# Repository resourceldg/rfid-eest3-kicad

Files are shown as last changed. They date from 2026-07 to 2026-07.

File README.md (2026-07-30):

# Control de acceso RFID EEST3

Diseño electrónico en KiCad 10 para un sistema de acceso escolar basado en ESP32, RC522, sensores y control de cerradura de 12 V.

## Estado actual del proyecto

Hay una placa de prueba de 140 × 100 mm, doble cara, **ruteada y con el DRC
limpio**: 348 pistas, 8 vías, dos planos de masa separados que se tocan en un
solo punto, y ninguna infracción de margen, cobre, alivio térmico ni
serigrafía. Los tres "no conectados" que informa el DRC son deliberados.

**No está lista para fabricar.** Faltan las mediciones de banco, la
verificación mecánica de los conectores y, sobre todo, medir el módulo ESP32-S3
para borrar la hilera de pines que sobra en J13. Los tres bloqueos están
detallados en [PENDIENTES.md](rfid-control-acceso-eest3/PENDIENTES.md).

## Ver todo el circuito de un vistazo

Las seis hojas del esquema son el documento valido, pero estan separadas y la
hoja raiz no dibuja como se relacionan. Para eso esta
[RESUMEN_ELECTRICO.kicad_sch](rfid-control-acceso-eest3/RESUMEN_ELECTRICO.kicad_sch):
una sola hoja A2 con los 67 componentes, sus simbolos y valores, el cableado de
cada bloque y el ESP32 en el centro. Es documentacion y **no forma parte de la
jerarquia del proyecto**: se abre sola.

```sh
python3 tools/esquema_resumen.py     # regenera la hoja desde el netlist real
kicad-cli sch export pdf -o rfid-control-acceso-eest3/RESUMEN_ELECTRICO.pdf \
    rfid-control-acceso-eest3/RESUMEN_ELECTRICO.kicad_sch
```

El generador se verifica solo: exporta el netlist de la hoja que acaba de
escribir y lo compara nodo por nodo contra el de las seis hojas. Si no coincide,
falla.

## Documentos de referencia

- Qué falta para fabricar: [rfid-control-acceso-eest3/PENDIENTES.md](rfid-control-acceso-eest3/PENDIENTES.md)
- Revisión técnica y riesgos: [rfid-control-acceso-eest3/INFORME_ESQUEMA.md](rfid-control-acceso-eest3/INFORME_ESQUEMA.md)
- Mediciones que faltan: [rfid-control-acceso-eest3/CHECKLIST_PREPCB.md](rfid-control-acceso-eest3/CHECKLIST_PREPCB.md)
- Por qué el cobre está donde está: [rfid-control-acceso-eest3/GUIA_RUTEO.md](rfid-control-acceso-eest3/GUIA_RUTEO.md)

## Próximo paso recomendado

Medir la separación real entre hileras del ESP32-S3 DevKit y borrar la hilera
sobrante de J13. Es el único bloqueo que no necesita instrumental: alcanza con
un calibre y el módulo en la mano.

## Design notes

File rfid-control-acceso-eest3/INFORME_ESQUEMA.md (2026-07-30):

# Informe técnico — Control de acceso RFID EEST3

Fecha: 2026-07-29  
Etapa: PCB prototipo Rev. A — transferencia y prelayout autorizados; ruteo no autorizado.

Datos físicos y comerciales disponibles:

- Marca publicada: Roa/Olipe SEB.
- Modelo publicado: 150.
- Tipo: cerradura eléctrica empotrable para portero eléctrico.
- Alimentación confirmada físicamente: 12 VCC.
- Consumo nominal confirmado: 1,8 A.
- Potencia nominal: 12 V × 1,8 A = 21,6 W.
- Fuente disponible: 12 VCC / 2,5 A (30 W).
- Pendientes: medición de corriente de arranque y comprobación térmica
  del MOSFET.

## Arquitectura implementada

El esquema se organizó jerárquicamente en seis bloques:

1. Alimentación y protección de 12 V, buck a 5 V y distribución de 3,3 V.
2. Controlador ESP32-S3-DevKitC-1 N16R8 de 44 pines representado mediante
   dos conectores funcionales de 1×22.
3. Lector RC522 representado mediante conector funcional de ocho vías.
4. Sensor reed, PIR opcional y entrada futura de sensor de gabinete.
5. LEDs de estado y buzzer con etapa MOSFET.
6. Etapa MOSFET canal N low-side para la cerradura inductiva de 12 VCC.

Las redes globales principales son `+12V_IN`, `+12V_LOCK`, `+5V`, `+3V3`
y `GND`. El RC522 solo está conectado a `+3V3`.

## Componentes

### Alimentación

- J1: entrada de 12 V.
- D1: protección serie Schottky, selección pendiente.
- F1: fusible lento o PTC de aproximadamente 2,5 A, valor preliminar;
  debe validarse después de medir la corriente de arranque.
- C1: 1000 µF / 25 V preliminar como reserva local de 12 V.
- C2: 100 nF preliminar.
- J2: interfaz funcional para módulo buck 12 V a 5 V.
- C3: 470 µF / 10 V preliminar en la salida de 5 V.
- C4: 100 nF preliminar.
- D5: TVS bidireccional para la línea de 12 V, selección pendiente.

### Controlador y RFID

- J13: representación unificada de 44 contactos (dos hileras de 22) del
  `ESP32_S3_DEVKITC1_N16R8_44PIN`, basada en el pinout del
  ESP32-S3-DevKitC-1. La equivalencia mecánica del clon YD-ESP32-S3 sigue
  pendiente de medición.
- C5: desacoplamiento de 100 nF preliminar.
- J5: interfaz funcional RC522; orden físico `PENDIENTE_DATASHEET`.
- C6: desacoplamiento de 100 nF preliminar.
- C9: reserva local de 10 µF preliminar.
- R9/R10/R11/R12: 33 Ω serie en `RFID_SS`, `RFID_SCK`, `RFID_MOSI` y
  `RFID_RST`, respectivamente.

### Sensores

- J6: reed de puerta, previsto para contacto normalmente cerrado.
- R1: pull-up 10 kΩ preliminar.
- C7: filtro 100 nF preliminar.
- J7: alimentación y contacto NC de alarma del DSC LC-100.
- J8: sensor óptico/de gabinete futuro.
- J10: contacto NC de tamper del DSC LC-100.
- R2: pull-up externo 10 kΩ para `CABINET_SENSOR` en GPIO6.
- D6: TVS para `DOOR_REED`, selección 3,3 V pendiente.
- D7: TVS preliminar sobre `PIR_CONTACT`; selección pendiente.
- D8: TVS para `CABINET_SENSOR`, selección 3,3 V pendiente.
- C8: filtro de 100 nF preliminar para `CABINET_SENSOR`.
- R13/R15: pull-ups externos de 10 kΩ para alarma y tamper.
- R14/R16: resistencias serie de 1 kΩ hacia GPIO5 y GPIO7.
- C10/C11: filtros de 100 nF desde `PIR_IN` y `PIR_TAMPER` a GND.

### Señalización

- R3/D2: LED verde con 330 Ω preliminar.
- R4/D3: LED rojo con 330 Ω preliminar.
- BZ1: `PENDIENTE_TIPO_BUZZER`.
- Q1, R5 y R6: driver MOSFET, 100 Ω serie y 10 kΩ pull-down.

### Cerradura

- J9: cerradura inductiva confirmada de 12 VCC, 1,8 A y 21,6 W.
- Q2: AO3400A preliminar, MOSFET canal N de nivel lógico.
- R7: 100 Ω en serie con el gate.
- R8: 10 kΩ entre gate y `GND_POWER`.
- D4: SS3A4 preliminar, Schottky de 3 A / 40 V.
- NT1: unión explícita en estrella entre `GND_POWER` y `GND`.

Todos los footprints están asignados y resueltos contra bibliotecas reales de KiCad 10; no queda ningún `PLACEHOLDER_NO_FABRICAR`. El único footprint local es `rfid_eest3:ESP32-S3-44P_SOCKET_DUAL_22.86_25.40`.

## Presupuesto de alimentación de la placa

El consumo de la electrónica todavía es una estimación porque faltan la
revisión física exacta del clon ESP32-S3, PIR, buzzer y buck.

| Carga | Reserva estimada | Potencia aproximada |
|---|---:|---:|
| ESP32 DevKit, incluyendo picos de radio y regulador | 500 mA a 5 V | 2,50 W |
| RC522 y pérdidas de regulación asociadas | 50 mA a 3,3 V | 0,17 W |
| DSC LC-100 y sensores externos | consumo pendiente a 12 V | debe medirse |
| Dos LEDs | 20 mA total a 3,3 V | 0,07 W |
| Buzzer | 100 mA a 5 V | 0,50 W |
| Margen/pérdidas del buck | eficiencia supuesta 85 % | aproximadamente 0,6 W |

La electrónica de baja tensión demanda aproximadamente 0,4 A desde 12 V.
Sumada a la cerradura, la corriente nominal estimada es aproximadamente
2,2 A. La fuente de 12 VCC / 2,5 A puede utilizarse para el prototipo, pero
deja solamente unos 0,3 A de margen nominal y debe verificarse durante el
arranque y la activación de la cerradura.

Para la instalación definitiva se recomienda una fuente regulada de
12 V / 4 A o superior, con protección y respuesta transitoria apropiadas.

## Etapa principal de cerradura 12 VCC

La cerradura está conectada entre `+12V_LOCK` y `LOCK_OUT`.
El drain de Q2 se conecta a `LOCK_OUT`; el source, a `GND_POWER`.
`LOCK_GATE` llega al gate mediante R7 de 100 Ω y R8 mantiene el gate apagado
con 10 kΩ hacia `GND_POWER`.

D4 está conectado en paralelo con la carga inductiva: cátodo hacia
`+12V_LOCK` y ánodo hacia `LOCK_OUT`. La selección preliminar es SS3A4,
3 A / 40 V.

Q2 se mantiene preliminarmente como AO3400A. Usando 1,8 A y
`RDS(on) = 48 mΩ`, la disipación conductiva teórica es:

`P = I² × R = (1,8 A)² × 0,048 Ω ≈ 0,156 W`.

Este cálculo no sustituye la comprobación térmica, el análisis del
encapsulado ni la verificación de `RDS(on)` a la tensión de gate real.

## Protección de sobrecorriente

F1 quedó como `T3.15A_5x20_LITTELFUSE_215`. ATENCIÓN: 3,15 A no protege una fuente de 2,5 A, que pliega antes; hay que reconciliar el valor del fusible con la fuente elegida.
No debe utilizarse una protección rápida de 2 A porque podría actuar durante
el funcionamiento nominal. La elección definitiva depende de medir la
corriente de arranque y revisar la curva tiempo-corriente.

## Retornos y filtrado

El esquema distingue:

- `GND_POWER`: retorno de Q2, cerradura, TVS de alimentación y capacitores
  de 12 V;
- `GND`: retorno lógico de buck, ESP32, RC522, sensores y señalización;
- NT1 `STAR_GND`: única unión lógica entre ambos retornos, próxima a la
  entrada de alimentación.

La masa es común porque Q2 es controlado desde el ESP32. El retorno de
1,8 A de la cerradura debe mantenerse físicamente separado del retorno
lógico y unirse a éste solamente en NT1, cerca de la entrada de alimentación.

Filtrado preliminar:

- 1000 µF / 25 V más 100 nF sobre 12 V;
- 470 µF / 10 V más 100 nF sobre 5 V;
- 100 nF locales en ESP32 y RC522.

Los electrolíticos deben seleccionarse por ESR, ripple, temperatura y
tolerancia. Estos valores reducen transitorios breves pero no sustituyen una
fuente con margen ni una distribución de masa correcta.

## Controlador ESP32-S3

Controlador confirmado por la publicación:

- familia ESP32-S3;
- placa ESP32-S3-DevKitC-1 N16R8 o clon compatible YD-ESP32-S3;
- flash de 16 MB;
- PSRAM de 8 MB;
- 44 pines físicos, 22 por lado;
- representación temporal:
  `ESP32_S3_DEVKITC1_N16R8_44PIN`.

No se utiliza ningún símbolo ni pinout de ESP32-WROOM-32 clásico de 30 o
38 pines. No se asume que el clon tenga las dimensiones mecánicas de la
placa oficial.

Restricciones aplicadas:

- GPIO22, GPIO23, GPIO24 y GPIO25 no existen en ESP32-S3.
- GPIO26 a GPIO32 quedan excluidos por su relación con flash/PSRAM.
- GPIO33 a GPIO37 quedan excluidos por la PSRAM de la variante N16R8.
- GPIO0, GPIO3, GPIO45 y GPIO46 quedan excluidos por strapping.
- GPIO19 y GPIO20 quedan reservados para USB nativo.
- GPIO43 y GPIO44 quedan reservados para UART de diagnóstico.
- GPIO38 se evita porque puede controlar el LED RGB según la revisión.

Continúan como `PENDIENTE_MEDICIÓN`: separación entre hileras, dimensiones,
posición de ambos USB-C del clon, distancia de los pines al borde, botones y
orientación de la antena.

## Mapa GPIO

| Señal | GPIO | Uso |
|---|---:|---|
| RFID_SCK | 12 | salida SPI; R10 = 33 Ω |
| RFID_MISO | 13 | entrada SPI |
| RFID_MOSI | 11 | salida SPI; R11 = 33 Ω |
| RFID_SS | 10 | salida chip-select; R9 = 33 Ω |
| RFID_RST | 9 | salida reset; R12 = 33 Ω |
| DOOR_REED | 4 | entrada con pull-up externo |
| PIR_IN | 5 | entrada desde contacto NC, serie 1 kΩ y filtro 100 nF |
| CABINET_SENSOR | 6 | entrada con pull-up externo |
| PIR_TAMPER | 7 | entrada desde contacto NC, serie 1 kΩ y filtro 100 nF |
| LED_OK | 15 | salida |
| LED_ERROR | 16 | salida |
| BUZZER | 17 | salida hacia driver |
| LOCK_GATE | 18 | salida hacia driver |

## Sensor PIR DSC LC-100

El sensor confirmado es un DSC LC-100 alimentado desde `+12V_AUX` y GND.
La alimentación está separada conceptualmente de las señales de alarma y
tamper, que son contactos secos de relé normalmente cerrados.

La interfaz física quedó dividida en tres borneras independientes:

- J11 `PIR_PWR`: pin 1 a `+12V_AUX`, pin 2 a GND;
- J12 `PIR_ALARM`: pin 1 COM a GND, pin 2 NC a `PIR_CONTACT`;
- J10 `PIR_TAMPER`: pin 1 T1 a `PIR_TAMPER_CONTACT`, pin 2 T2 a GND.

Contacto de alarma:

- COM a GND;
- NC a `PIR_CONTACT`;
- R13 de 10 kΩ entre `PIR_CONTACT` y `+3V3`;
- R14 de 1 kΩ entre `PIR_CONTACT` y `PIR_IN`;
- C10 de 100 nF entre `PIR_IN` y GND.

En estado normal el contacto está cerrado y GPIO5 permanece en nivel bajo.
Una alarma, corte del cable o desconexión abre el circuito y el pull-up lleva
GPIO5 a nivel alto.

Contacto tamper:

- un terminal a GND;
- otro terminal a `PIR_TAMPER_CONTACT`;
- R15 de 10 kΩ entre `PIR_TAMPER_CONTACT` y `+3V3`;
- R16 de 1 kΩ entre `PIR_TAMPER_CONTACT` y `PIR_TAMPER`;
- C11 de 100 nF entre `PIR_TAMPER` y GND.

La rama `+12V_AUX` se deriva de `+12V_LOCK` mediante F2
`AUX_PROTECTION_PENDING`. Para el DSC LC-100 solo quedan pendientes la
numeración física exacta de sus borneras, la medición del cableado y la
ubicación física del sensor.

## RC522

El conector funcional J5 representa, en este orden lógico:

1. `RFID_SS`
2. `RFID_SCK`
3. `RFID_MOSI`
4. `RFID_MISO`
5. `RFID_IRQ`, marcado explícitamente No Connect
6. `GND`
7. `RFID_RST`
8. `+3V3`

Este orden no autoriza fabricar un conector físico. Debe verificarse el módulo
real y su datasheet antes de asignar footprint.

## Datos pendientes

- Capacidad de corriente disponible en 3,3 V de la revisión física del
  ESP32-S3 DevKit/clon.
- Correspondencia física final del clon YD-ESP32-S3 con los headers oficiales.
- Pinout físico exacto del módulo RC522.
- Modelo del buck y disposición de terminales.
- Medir la corriente de arranque de la cerradura.
- Comprobar térmicamente Q2 en las condiciones reales de activación.
- Confirmar la `RDS(on)` del AO3400A a la tensión de gate real del ESP32.
- Curva exacta del fusible lento o PTC de placa.
- Numeración física exacta de las borneras del DSC LC-100.
- Medición del cableado del DSC LC-100.
- Ubicación física del DSC LC-100.
- Tipo, tensión y corriente del buzzer; necesidad de diodo si fuera inductivo.

## Lista de comprobación física previa a footprints

Estados utilizados:

- `CONFIRMADO`: dato físico disponible y utilizable.
- `PENDIENTE_MEDICIÓN`: requiere medir el ejemplar real o el montaje.
- `PENDIENTE_MODELO`: requiere seleccionar o identificar el componente y
  consultar su documentación.

No debe asignarse ningún footprint hasta completar los datos aplicables de
esta lista.

Conteo verificado de filas de comprobación —sin contar la leyenda de
estados—:

- 10 `CONFIRMADO`.
- 24 `PENDIENTE_MEDICIÓN`.
- 21 `PENDIENTE_MODELO`.
- Total: **55 verificaciones**.

El conteo anterior de 7, 25 y 26 incluía una vez adicional cada estado por
su aparición en la leyenda. No se encontraron filas duplicadas y no se
eliminó ninguna verificación válida.

| Estado | Bloque | Dato físico o eléctrico | Criterio de aceptación / acción requerida |
|---|---|---|---|
| `CONFIRMADO` | ESP32-S3 DevKit | Familia y variante objetivo | ESP32-S3-DevKitC-1 N16R8 o clon YD-ESP32-S3 compatible; 16 MB flash y 8 MB PSRAM. |
| `CONFIRMADO` | ESP32-S3 DevKit | Cantidad de pines | 44 pines, 22 por hilera. |
| `PENDIENTE_MEDICIÓN` | ESP32-S3 DevKit | Separación entre hileras | Medir entre centros con calibre; no asumir la dimensión oficial para el clon. |
| `PENDIENTE_MEDICIÓN` | ESP32-S3 DevKit | Paso de pines | Medir y contrastar con el módulo físico antes de crear el footprint. |
| `PENDIENTE_MEDICIÓN` | ESP32-S3 DevKit | Largo, ancho y altura máxima | Medir placa, componentes salientes y conectores montados. |
| `PENDIENTE_MEDICIÓN` | ESP32-S3 DevKit | USB, botones y antena | Medir ambos USB-C del clon, EN, BOOT, orientación de antena y distancias a bordes. |
| `CONFIRMADO` | ESP32-S3 DevKit | Pinout lógico de referencia | J3/J4 representan los headers J1/J3 del DevKitC-1 oficial; validar continuidad contra el clon físico antes de PCB. |
| `PENDIENTE_MEDICIÓN` | RC522 | Orden real del conector | Verificar continuidad y serigrafía pin por pin; el orden lógico de J5 no define el orden físico. |
| `PENDIENTE_MEDICIÓN` | RC522 | Paso, posición y orientación | Medir conector, distancia a bordes y sentido de inserción. |
| `PENDIENTE_MEDICIÓN` | RC522 | Dimensiones y agujeros | Medir largo, ancho, altura y centros de fijación del módulo real. |
| `PENDIENTE_MODELO` | RC522 | Zona de exclusión de antena | Obtener la recomendación del fabricante sobre cobre, planos de masa, metal y batería/cerradura. |
| `PENDIENTE_MEDICIÓN` | RC522 | Separación en el montaje | Validar experimentalmente lectura RFID con la antena alejada de cobre, cableado de 1,8 A, MOSFET, buck y cerradura. |
| `PENDIENTE_MODELO` | Buck | Modelo exacto | Seleccionar módulo o regulador y conseguir plano mecánico y datasheet. |
| `PENDIENTE_MODELO` | Buck | Entrada, salida y polaridad | Confirmar rango de entrada, tensión de salida regulada a 5 V y orden real de terminales. |
| `PENDIENTE_MEDICIÓN` | Buck | Dimensiones y altura | Medir PCB, componentes, inductor, disipador, potenciómetro y agujeros. |
| `PENDIENTE_MEDICIÓN` | Buck | Terminales | Medir paso, posición, orientación y acceso para ajuste o cableado. |
| `PENDIENTE_MODELO` | Buck | Capacidad de corriente | Debe cubrir la electrónica con picos de radio y margen térmico; objetivo mínimo recomendado: 5 V / 1 A continuo, sujeto al consumo real. |
| `CONFIRMADO` | MOSFET Q2 | Corriente nominal de carga | 1,8 A con la cerradura activada. |
| `CONFIRMADO` | MOSFET Q2 | Cálculo conductivo preliminar | Para 48 mΩ: `(1,8 A)² × 0,048 Ω ≈ 0,156 W`. |
| `PENDIENTE_MODELO` | MOSFET Q2 | AO3400A y fabricante | Verificar datasheet del fabricante concreto, `VDS`, corriente, SOA y `RDS(on)` garantizada con `VGS` de 2,5 V o compatible con 3,3 V. No aceptar únicamente el dato a 10 V. |
| `PENDIENTE_MEDICIÓN` | MOSFET Q2 | Gate real | Medir la tensión de gate en nivel alto con el ESP32 y la etapa funcionando. |
| `PENDIENTE_MEDICIÓN` | MOSFET Q2 | Temperatura | Medir temperatura ambiente y elevación de Q2 durante el peor tiempo de activación. |
| `PENDIENTE_MEDICIÓN` | MOSFET Q2 | Cobre disponible | Definir área de cobre, vías térmicas y espesor de cobre antes de validar SOT-23. |
| `PENDIENTE_MODELO` | MOSFET Q2 | Alternativa térmica | Comparar AO3400A SOT-23 con un MOSFET lógico en SO-8 térmico, PowerPAK/LFPAK o DPAK; elegir por `RDS(on)` a gate real, SOA, disipación, disponibilidad y montaje educativo. |
| `PENDIENTE_MEDICIÓN` | MOSFET Q2 | Transitorios | Medir `VDS` durante apertura y cierre; mantener margen respecto de la tensión máxima del dispositivo. |
| `CONFIRMADO` | Gate Q2 | Red de control | R7 = 100 Ω y R8 = 10 kΩ pull-down. |
| `CONFIRMADO` | Flyback D4 | Requisitos preliminares | Schottky de al menos 3 A y 40 V; cátodo a `+12V_LOCK`, ánodo a `LOCK_OUT`. |
| `PENDIENTE_MODELO` | Flyback D4 | SS3A4 exacto | Confirmar fabricante, código completo, corriente media, corriente de pulso, tensión inversa, fuga y curva térmica. |
| `PENDIENTE_MODELO` | Flyback D4 | Encapsulado | Confirmar encapsulado y dimensiones reales; el nombre comercial no autoriza asumir SMA/SMB. |
| `PENDIENTE_MEDICIÓN` | Flyback D4 | Régimen térmico | Comprobar temperatura y energía por maniobra con la corriente y frecuencia reales. |
| `PENDIENTE_MEDICIÓN` | Flyback D4 | Ubicación física | Reservar ubicación inmediatamente junto a J9 y al lazo de corriente de la cerradura; minimizar el área del lazo. |
| `CONFIRMADO` | Protección | Fuente de prototipo | 12 VCC / 2,5 A; utilizable para el prototipo con margen nominal limitado. |
| `CONFIRMADO` | Protección | Fuente definitiva recomendada | Fuente regulada de 12 V / 4 A o superior. |
| `PENDIENTE_MEDICIÓN` | Protección | Corriente de arranque | Medir pico, duración y repetibilidad antes de fijar fusible o PTC. |
| `PENDIENTE_MODELO` | Protección | Fusible lento | Comparar corriente nominal, curva tiempo-corriente, poder de corte, tensión máxima y portafusible. |
| `PENDIENTE_MODELO` | Protección | PTC | Comparar corriente de mantenimiento, corriente de disparo, tensión máxima, resistencia fría/caliente y tiempo de recuperación. |
| `PENDIENTE_MODELO` | Protección | Separación por ramas | Proponer una protección para la electrónica después de la derivación y otra para `+12V_LOCK`; sus valores se eligen después de medir consumos y arranque. |
| `PENDIENTE_MODELO` | Conectores de potencia | Corriente nominal | J1 y J9 deben superar la corriente continua y de arranque con margen; objetivo preliminar mínimo 5 A por contacto. |
| `PENDIENTE_MODELO` | Conectores de potencia | Paso y cable | Seleccionar paso, sección admitida, temperatura, tensión y sistema de tornillo/resorte según el cable real. |
| `PENDIENTE_MODELO` | Conectores | Polaridad y retención | Elegir conectores polarizados o rotulado inequívoco; definir punteras, terminales y alivio de tracción. |
| `PENDIENTE_MEDICIÓN` | Conectores | Separación física | Definir distancia entre potencia, señales, antena y bordes; evitar recorridos paralelos largos entre `LOCK_OUT` y sensores. |
| `PENDIENTE_MODELO` | Reed | Modelo físico | Confirmar contacto NC, corriente/tensión de contacto, cable, carcasa, fijación y conector. |
| `CONFIRMADO` | PIR DSC LC-100 | Modelo e interfaz | Alimentación a 12 V y contactos secos NC independientes para alarma y tamper; no es una salida electrónica de 5 V. |
| `PENDIENTE_MEDICIÓN` | PIR DSC LC-100 | Instalación física | Confirmar numeración de borneras, medir cableado y definir ubicación física. |
| `PENDIENTE_MODELO` | Sensor de gabinete | Modelo físico | Confirmar tipo de salida, tensión, consumo, cable y conector. |
| `PENDIENTE_MODELO` | Buzzer | Tipo físico | Confirmar activo/pasivo, tensión, corriente, polaridad, diámetro, altura, paso y necesidad de diodo. |
| `PENDIENTE_MODELO` | LEDs | Formato | Elegir THT/SMD, color, corriente objetivo, polaridad, dimensiones y visibilidad a través de la caja. |
| `PENDIENTE_MODELO` | Capacitores | Tecnología y tensión | Confirmar electrolíticos de 1000 µF/25 V y 470 µF/10 V, ESR, ripple y temperatura; revisar margen de tensión. |
| `PENDIENTE_MEDICIÓN` | Capacitores | Geometría | Medir diámetro, altura y paso; comprobar polaridad y espacio de montaje. |
| `PENDIENTE_MODELO` | Capacitores | Cerámicos | Elegir encapsulado, tensión, dieléctrico y tolerancia para los 100 nF. |
| `PENDIENTE_MEDICIÓN` | Mecánica | Dimensiones de placa | Definir largo, ancho, altura máxima y zonas prohibidas de la caja. |
| `PENDIENTE_MEDICIÓN` | Mecánica | Fijación | Definir cantidad, diámetro, posición y despeje de agujeros, separadores y tornillos. |
| `PENDIENTE_MODELO` | Mecánica | Caja | Seleccionar material, ventilación, grado de protección, acceso de mantenimiento y puesta a tierra si correspondiera. |
| `PENDIENTE_MEDICIÓN` | Mecánica | Acceso | Validar acceso a USB, botones, fusible, buck, conectores y tornillos sin desmontaje peligroso. |
| `PENDIENTE_MEDICIÓN` | Mecánica/RFID | Separación funcional | Ensayar distancia entre antena RC522, etapa MOSFET, buck, cableado de cerradura y cualquier pieza metálica de la caja. |

### Evaluación del MOSFET

- El IRFZ44N queda descartado para control directo desde un GPIO de 3,3 V.
- Su `RDS(on)` está garantizada únicamente con `VGS = 10 V`.
- Su `VGS(th)` de 2 a 4 V indica solamente el comienzo de conducción y no
  representa plena conducción ni baja resistencia para manejar 1,8 A.
- Solo podría utilizarse con un driver de gate que entregue aproximadamente
  10 V, lo que agregaría componentes y complejidad innecesarios.
- Se mantiene el AO3400A como selección preliminar mientras se evalúa una
  alternativa logic-level de encapsulado mayor, con `RDS(on)` garantizada a
  una tensión compatible con el GPIO de 3,3 V.

### Relevamiento físico necesario

| Componente | Marca/modelo | Foto frontal | Foto posterior | Largo | Ancho | Altura | Paso entre pines | Separación entre hileras | Orden físico de pines | Tensión | Corriente | Estado de confirmación |
|---|---|---|---|---|---|---|---|---|---|---|---|---|
|  |  |  |  |  |  |  |  |  |  |  |  |  |
|  |  |  |  |  |  |  |  |  |  |  |  |  |
|  |  |  |  |  |  |  |  |  |  |  |  |  |
|  |  |  |  |  |  |  |  |  |  |  |  |  |
|  |  |  |  |  |  |  |  |  |  |  |  |  |
|  |  |  |  |  |  |  |  |  |  |  |  |  |

### Tratamiento propuesto de las advertencias ERC

- `RFID_IRQ`: IRQ no se utiliza y el pin 5 de J5 quedó marcado
  explícitamente como No Connect.
- `PIR_IN`: la advertencia quedó resuelta mediante el contacto seco NC del
  DSC LC-100, R13/R14 y C10.
- `PIR_TAMPER`: contacto seco NC supervisado mediante R15/R16 y C11.
- No se agregaron exclusiones para ocultar advertencias.

## ERC

Comando: `kicad-cli sch erc`

Resultado final (2026-07-29 07:36:26): **0 errores y 0 advertencias**.

No quedan advertencias aceptadas. `RFID_IRQ` está marcado No Connect y las
dos entradas del DSC LC-100 están conectadas mediante sus respectivas redes
de pull-up, protección serie y filtrado.

No se agregaron exclusiones individuales ni `PWR_FLAG` innecesarios. KiCad
informó como clases de comprobación ignoradas por la configuración:
`Global label only appears once in the schematic`,
`Four connection points are joined together`, `SPICE model issue` y
`Assigned footprint doesn't match footprint filters`. No se modificó esa
configuración durante esta actualización.

## Riesgos eléctricos

- Una numeración incorrecta de las borneras del LC-100 podría intercambiar
  alimentación y contactos; debe verificarse físicamente antes de energizar.
- La corriente de arranque aún desconocida puede producir caídas de tensión
  o disparar la protección.
- La fuente disponible deja solamente unos 0,3 A de margen nominal después
  de sumar la cerradura y la estimación de la electrónica.
- La disipación calculada de Q2 no incluye transitorios ni aumento de
  `RDS(on)` por temperatura.
- El retorno de 1,8 A puede reiniciar o perturbar al ESP32 si no se respeta
  la separación física y la unión en estrella.
- La salida de 3,3 V del DevKit debe verificarse antes de alimentar el RC522.
- Los TVS agregados son topologías preliminares: tensión de trabajo, clamp,
  energía, fuga y capacitancia deben seleccionarse con los cables y módulos reales.

## Preparación de footprints y fabricación

La PCB tiene los 71 footprints colocados sobre un contorno de 140 × 100 mm, sin pistas, vías ni planos. El floorplan se recalculó a partir de la posición real de los pines de J13. Queda pendiente ejecutar **Update PCB from Schematic** en la GUI para transferir los footprints nuevos (KiCad no expone esa operación por CLI). Los nombres se verificaron contra el
índice de footprints de KiCad 10, sincronizado el 2026-07-29: 155 bibliotecas y
15 447 footprints.

Estados:

- `CONFIRMADO`: componente físico y encapsulado suficientemente definidos.
- `PRELIMINAR`: footprint existente y eléctricamente plausible, pendiente de
  comparación con el componente comprado.
- `PENDIENTE_MEDICIÓN`: no debe asignarse hasta medir o identificar el modelo.

| Referencia | Componente | Valor | Footprint propuesto | Estado | Corriente o tensión relevante | Observaciones de montaje | Riesgo de pinout incorrecto |
|---|---|---|---|---|---|---|---|
| R1–R17 | Resistencias THT | 33 Ω, 100 Ω, 330 Ω, 1 kΩ y 10 kΩ según referencia | `Resistor_THT:R_Axial_DIN0207_L6.3mm_D2.5mm_P10.16mm_Horizontal` | PRELIMINAR | 3,3 V/5 V; R7 es serie de gate | DIN0207, 0,25 W, cuerpo 6,3 × 2,5 mm y paso 10,16 mm; confirmar potencia y tamaño real | Bajo: componente no polarizado |
| C2, C4–C8, C10, C11 | Cerámicos THT | 100 nF | `Capacitor_THT:C_Disc_D5.0mm_W2.5mm_P5.00mm` | PRELIMINAR | Confirmar tensión nominal; C2/C4 están en alimentación | Disco 5 × 2,5 mm y paso 5 mm; comparar con el lote comprado | Bajo: no polarizado |
| C1 | Electrolítico radial | 1000 µF / 25 V preliminar | Radial THT por definir | PENDIENTE_MEDICIÓN | 25 V mínimo indicado; entrada de 12 V | Medir diámetro, altura, paso, ESR y ripple; respetar polaridad | Alto si se invierte polaridad o se asume el paso |
| C3 | Electrolítico radial | 470 µF / 10 V preliminar | Radial THT por definir | PENDIENTE_MEDICIÓN | 10 V mínimo indicado; salida de 5 V | Medir diámetro, altura, paso, ESR y ripple; respetar polaridad | Alto si se invierte polaridad o se asume el paso |
| C9 | Capacitor local RC522 | 10 µF preliminar | Radial THT o cerámico por definir | PENDIENTE_MEDICIÓN | 3,3 V | Definir tecnología, polaridad, diámetro/encapsulado y paso | Medio |
| D2, D3 | LED verde/rojo | 5 mm | `LED_THT:LED_D5.0mm` | PRELIMINAR | Corriente limitada por R3/R4 de 330 Ω | Paso 2,54 mm; orientar cara plana/cátodo y asegurar visibilidad desde la caja | Alto si se intercambian A/K |
| Q2 | MOSFET de cerradura | AO3400A preliminar | `Package_TO_SOT_SMD:SOT-23`, asignado al esquema | PRELIMINAR | 12 V, 1,8 A; disipación conductiva teórica ≈0,156 W | Datasheet oficial AOS y símbolo verificados: 1=G, 2=S, 3=D. Validar térmicamente el SOT-23 | Crítico si se compra una variante con pinout diferente |
| Q2 alternativa | MOSFET logic-level reparable | Modelo TO-220 pendiente | `Package_TO_SOT_THT:TO-220-3_Vertical` | PENDIENTE_MEDICIÓN | ≥30 V, ≥5 A y `RDS(on)` garantizada a 2,5/3,3 V | Alternativa para montaje, disipación y reparación; no reemplaza al AO3400A sin aprobación | Crítico: seleccionar modelo real y verificar G-D-S |
| — | MOSFET descartado | IRFZ44N | No asignar | CONFIRMADO | No garantiza conducción adecuada con gate de 3,3 V | Solo sería utilizable con driver de gate cercano a 10 V | Crítico si se conecta directamente al GPIO |
| D4 | Flyback de cerradura | SS3A4, 3 A / 40 V preliminar | `Diode_SMD:D_SMA` | PRELIMINAR | Pulso inicial de al menos 1,8 A | SMA/DO-214AC; colocar junto a J9; pad 1 es K y pad 2 es A en el esquema actual | Alto: confirmar encapsulado SS3A4 y polaridad física |
| Q1 | Driver de buzzer NMOS | AO3400A preliminar | `Package_TO_SOT_SMD:SOT-23`, asignado al esquema | PRELIMINAR | Buzzer a +5 V; corriente pendiente | GPIO17 → R5 100 Ω → gate; R6 10 kΩ gate-source; source a GND; drain al negativo de BZ1. Datasheet oficial AOS y símbolo verificados: 1=G, 2=S, 3=D | Crítico si se adapta por apariencia en vez de verificar pads |
| D9 | Protección opcional del buzzer | `DNP_HASTA_CONFIRMAR_TIPO_BUZZER` | Sin footprint hasta confirmar el buzzer | PENDIENTE_MEDICIÓN | Cátodo a +5 V; ánodo al drain/negativo del buzzer | Montar solamente si BZ1 es magnético/inductivo. Un piezoeléctrico normalmente no requiere flyback | Alto: tipo y polaridad pendientes |
| BZ1 | Buzzer THT | `BUZZER?` | `Buzzer_Beeper:Buzzer_12x9.5RM7.6` | PRELIMINAR | 5 V; consumo pendiente | Diámetro 12 mm, altura 9,5 mm y paso 7,6 mm; confirmar buzzer activo/pasivo, tensión y polaridad | Alto si polarizado o si el paso no coincide |
| J1 | Entrada de alimentación | 12 VCC / 2,5 A prototipo | Bornera THT 1×2, paso 5,08 mm, modelo ≥5 A por definir | PENDIENTE_MEDICIÓN | Mínimo 5 A por contacto solicitado | Los alias `TerminalBlock:TerminalBlock_bornier-2_P5.08mm` no existen en las bibliotecas KiCad 10 instaladas; elegir footprint del fabricante comprado | Alto: dimensiones, taladro y orientación |
| J9 | Cerradura | 12 VCC / 1,8 A | Bornera THT 1×2, paso 5,08 mm, modelo ≥5 A por definir | PENDIENTE_MEDICIÓN | Mínimo 5 A por contacto solicitado | Preferir bornera con margen térmico, cable adecuado y acceso frontal; ubicar D4 junto a ella | Alto: polaridad y capacidad real |
| J6, J8 | Reed y gabinete | Contactos externos | Bornera THT, paso esperado 5,08 mm, modelo por definir | PENDIENTE_MEDICIÓN | Señales de 3,3 V y GND | Separar físicamente de J1/J9 y del lazo de cerradura; confirmar sección de cable | Medio |
| J10 | DSC LC-100 tamper | `PIR_TAMPER`, T1/T2 | Bornera THT 1×2, paso esperado 5,08 mm, sin asignar | PENDIENTE_MEDICIÓN | Contacto seco con pull-up a 3,3 V | T1 a `PIR_TAMPER_CONTACT`; T2 a GND | Alto: numeración física pendiente |
| J11 | DSC LC-100 alimentación | `PIR_PWR` | Bornera THT 1×2, paso esperado 5,08 mm, sin asignar | PENDIENTE_MEDICIÓN | +12V_AUX y GND | Conector independiente de las señales | Alto: polaridad y numeración física |
| J12 | DSC LC-100 alarma | `PIR_ALARM`, COM/NC | Bornera THT 1×2, paso esperado 5,08 mm, sin asignar | PENDIENTE_MEDICIÓN | Contacto seco con pull-up a 3,3 V | COM a GND; NC a `PIR_CONTACT`; conserva lógica fail-safe | Alto: identificar COM/NC físicamente |
| J2 | Módulo buck externo | `BUCK?` | Sin footprint de LM2596; interfaz de borneras por definir | PENDIENTE_MEDICIÓN | Entrada 12 V, salida 5 V/GND; capacidad mínima recomendada 1 A | Mantener módulo fuera de la PCB. Confirmar si J2 será una bornera de cuatro polos o dos borneras de dos polos y el orden físico | Alto |
| J3, J4 | Zócalos ESP32-S3 | 22 pines por lado | Dos `Connector_PinSocket_2.54mm:PinSocket_1x22_P2.54mm_Vertical` | PENDIENTE_MEDICIÓN | 5 V, 3,3 V y GPIO | Footprint de cada hilera verificado: 22 pads, paso 2,54 mm y largo entre centros 53,34 mm. Usar headers hembra y módulo removible | Crítico: separación entre hileras, orientación y correspondencia J3/J4 |
| J5 | RC522 externo | Header 1×8 | `Connector_PinHeader_2.54mm:PinHeader_1x08_P2.54mm_Vertical` | PRELIMINAR | Exclusivamente 3,3 V | 8 pads, paso 2,54 mm y 17,78 mm entre centros extremos; usar cable corto o header y verificar orden real del módulo | Crítico: el orden físico del RC522 sigue pendiente |
| D1 | Protección de polaridad | `SCHOTTKY?` | Por definir con el componente | PENDIENTE_MEDICIÓN | Debe soportar la corriente total y la tensión inversa | Seleccionar encapsulado por corriente, caída y disipación; no asumir diodo axial pequeño | Alto: A/K |
| D5 | TVS de entrada | `TVS_12V?` | Por definir con el componente | PENDIENTE_MEDICIÓN | Entrada 12 V y transitorios | Definir VRWM, potencia de pulso, encapsulado y polaridad si es unidireccional | Alto |
| D6, D8 | Protección de sensores | `TVS_3V3?` | Por definir con el componente | PENDIENTE_MEDICIÓN | Entradas GPIO de 3,3 V | Seleccionar baja fuga y capacitancia adecuada; colocar cerca de conectores | Alto |
| D7 | Protección PIR | `TVS_CONTACT_PENDING` | Por definir con el componente | PENDIENTE_MEDICIÓN | Contacto seco con pull-up de 3,3 V | Seleccionar tensión de trabajo y fuga compatibles con la entrada | Alto |
| F1 | Protección principal | `2.5A_SLOW_OR_PTC_PRELIM` | Portafusible o PTC por definir | PENDIENTE_MEDICIÓN | Corriente de arranque de cerradura aún pendiente | Elegir después de medir pico y curva; comprobar tensión, poder de corte y temperatura | Medio |
| F2 | Protección auxiliar | `AUX_PROTECTION_PENDING` | Portafusible o PTC por definir | PENDIENTE_MEDICIÓN | Consumo DSC LC-100 y rama AUX pendiente | Protección independiente de electrónica/sensor; seleccionar con el consumo real | Medio |
| NT1 | Unión estrella de masas | `STAR_GND` | `NetTie:NetTie-2_THT_Pad1.0mm` como opción documental | PRELIMINAR | Retorno de cerradura de 1,8 A | La geometría final debe imponer unión única cerca de la entrada; revisar si un net-tie THT es adecuado para la corriente | Medio |

### Decisiones mecánicas previas a PCB

| Decisión | Estado | Criterio antes de asignar footprints |
|---|---|---|
| Modelo físico de cada bornera | PENDIENTE_MEDICIÓN | Fabricante, código, corriente nominal, paso real, taladro, tamaño, orientación de entrada del cable y sección admitida |
| Borneras J1/J9 | PENDIENTE_MEDICIÓN | Certificar al menos 5 A por contacto; no aceptar el paso 5,08 mm como prueba suficiente de corriente |
| Interfaz DSC LC-100 | PENDIENTE_MEDICIÓN | Tres conectores de dos polos ya separados lógicamente: J11 alimentación, J12 alarma y J10 tamper. Falta confirmar numeración física |
| ESP32-S3 removible | PENDIENTE_MEDICIÓN | Medir paso, separación entre hileras, largo/ancho, voladizo, USB-C, botones, antena y orientación de pin 1 |
| RC522 externo | PENDIENTE_MEDICIÓN | Confirmar pin 1, paso y cable; definir soporte mecánico y zona sin cobre/metal alrededor y debajo de la antena |
| Zona RFID | PENDIENTE_MEDICIÓN | Definir distancia experimental a PCB, planos de masa, buck, MOSFET, cable de 1,8 A, cerradura y piezas metálicas |
| Buck externo | PENDIENTE_MEDICIÓN | Modelo, capacidad térmica, bornes IN/OUT, orden, acceso al ajuste y fijación fuera de la PCB principal |
| Q2 SOT-23 | PENDIENTE_MEDICIÓN | Validar mapa G-S-D, temperatura ambiente, cobre disipador, pulsos de cerradura y transitorios VDS |
| Alternativa Q2 TO-220 | PENDIENTE_MEDICIÓN | Elegir MOSFET logic-level real con `RDS(on)` garantizada a 2,5/3,3 V; confirmar G-D-S y método de fijación/disipador |
| Driver de buzzer Q1 | PRELIMINAR | AO3400A confirmado como selección común con Q2; footprint SOT-23 y orden 1=G, 2=S, 3=D verificados. Falta confirmar corriente y tipo del buzzer |
| Capacitores electrolíticos | PENDIENTE_MEDICIÓN | Medir diámetro, altura, paso y polaridad; verificar ESR, ripple y temperatura |
| Caja y placa | PENDIENTE_MEDICIÓN | Dimensiones máximas, agujeros, separadores, ventilación y acceso seguro a fusibles, USB y terminales |
| Separación potencia/lógica | PENDIENTE_MEDICIÓN | Reservar recorridos y retornos separados, unión estrella y distancia entre conectores de potencia y señales |
| Protección ESD/cables externos | PENDIENTE_MEDICIÓN | Seleccionar TVS con datos reales de cableado; ubicar protección en la entrada física de cada conector |

### Buzzer y protección opcional

## Plan de depuración inmediato para la rama claude

El objetivo de esta fase es convertir el esquema actual en un prototipo mejor validado antes de avanzar a una PCB de prueba.

1. Medir corriente de arranque y consumo estacionario de la cerradura de 12 V.
2. Validar el MOSFET y el flyback con margen térmico real y con la carga inductiva instalada.
3. Confirmar que la fuente de 12 V tenga margen suficiente para la cerradura y la electrónica simultáneamente.
4. Ajustar la ruta de retorno y la separación entre potencia y lógica para reducir ruido y caídas de tensión.
5. Verificar físicamente el pinout del ESP32-S3, el módulo RC522 y todas las borneras antes de asignar footprints finales.
6. Usar la checklist de depuración pre-PCB como gate de avance: [CHECKLIST_PREPCB.md](CHECKLIST_PREPCB.md).

Este plan es prioritario porque el mayor riesgo actual no está en el ERC, sino en la validación de potencia, protección y montaje físico.

Q1 permanece como MOSFET N-channel AO3400A, controlado directamente desde
`BUZZER`/GPIO17 mediante R5 de 100 Ω. R6 de 10 kΩ mantiene el gate apagado;
source va a GND, drain al terminal negativo de BZ1 y el positivo de BZ1 a
`+5V`. El mismo AO3400A se utiliza preliminarmente en Q1 y Q2 para simplificar
la BOM.

D9 está conectado en antiparalelo con BZ1, con cátodo a `+5V` y ánodo al
drain, pero su valor es `DNP_HASTA_CONFIRMAR_TIPO_BUZZER`:

- un buzzer magnético puede necesitar protección flyback;
- un buzzer piezoeléctrico normalmente no necesita ese diodo;
- el driver MOSFET sirve para buzzer activo o pasivo, pero el firmware será
  nivel fijo/intermitente para uno activo y PWM/tono para uno pasivo.

No debe sustituirse Q1 por 2N2222A.

### Requisitos y candidatas de borneras

Todas las borneras azules permanecen sin footprint. Se espera un paso de
5,08 mm, pero antes de asignar debe medirse:

- diámetro o sección de los pines;
- ancho y profundidad del cuerpo;
- distancia necesaria al borde de placa;
- orientación y acceso al tornillo;
- sección de cable admisible.

J1 y J9 deben soportar al menos 5 A por contacto. Las borneras de sensores
pueden tener una corriente nominal menor.

Candidatas verificadas en la biblioteca KiCad 10, todavía sin asignar:

| Candidata | Biblioteca completa | Datos de biblioteca | Estado |
|---|---|---|---|
| TB007-508-02 | `TerminalBlock_CUI:TerminalBlock_CUI_TB007-508-02_1x02_P5.08mm_Horizontal` | 2 polos, 10,8 × 10,2 mm, taladro 1,6 mm | PENDIENTE_MEDICIÓN |
| TB007-508-03 | `TerminalBlock_CUI:TerminalBlock_CUI_TB007-508-03_1x03_P5.08mm_Horizontal` | 3 polos, 15,8 × 10,2 mm, taladro 1,6 mm | PENDIENTE_MEDICIÓN |
| MKDS-1,5-2-5.08 | `TerminalBlock_Phoenix:TerminalBlock_Phoenix_MKDS-1,5-2-5.08_1x02_P5.08mm_Horizontal` | 2 polos, 10,2 × 9,8 mm, taladro 1,3 mm | PENDIENTE_MEDICIÓN |

Si ninguna coincide con la bornera física, se preparará posteriormente la
biblioteca local `rfid_eest3.pretty`. No se descargará ni copiará ningún
footprint sin contrastar primero todas las medidas.

### Estado de la PCB antes de transferencia

- Footprints: **0**.
- Redes: **0**.
- Segmentos/pistas: **0**.
- Vías: **0**.
- Zonas de cobre: **0**.
- Keepouts: **0**.
- Contorno de placa: no definido.
- `Update PCB from Schematic`: **no ejecutado**.

## PCB prototipo Rev. A — footprints y prelayout

Rama Git: `pcb-rev-a-prelayout`.

La transferencia desde el esquema fue ejecutada de forma controlada. No se
modificaron conexiones, redes, GPIO ni valores eléctricos. La placa supone
provisionalmente FR4 de 1,6 mm, dos capas (`F.Cu` y `B.Cu`) y cobre de 1 oz.
El espesor de cobre continúa siendo un requisito documental hasta definir el
fabricante.

### Auditoría de footprints aplicada

| Referencia | Valor / componente | Footprint aplicado o propuesto | Estado | Pinout comprobado | Riesgo mecánico y observaciones |
|---|---|---|---|---|---|
| R1–R17 | Resistencias THT 1/4 W | `Resistor_THT:R_Axial_DIN0207_L6.3mm_D2.5mm_P10.16mm_Horizontal` | CONFIRMADO | Sí, pads 1–2 | Confirmar potencia y diámetro reales antes de comprar |
| C2, C4–C8, C10, C11 | 100 nF THT | `Capacitor_THT:C_Disc_D5.0mm_W2.5mm_P5.00mm` | PRELIMINAR_REV_A | Sí | Verificar ancho y paso del capacitor adquirido |
| D2, D3 | LED THT 5 mm | `LED_THT:LED_D5.0mm` | PRELIMINAR_REV_A | Sí: pad 1 cátodo, pad 2 ánodo | Verificar polaridad física y altura |
| Q1, Q2 | AO3400A | `Package_TO_SOT_SMD:SOT-23` | PRELIMINAR_REV_A | Sí: 1=G, 2=S, 3=D | Q2 requiere ensayo térmico a 1,8 A y área de cobre; prever revisión robusta |
| D4 | SS3A4 3 A / 40 V | `Diode_SMD:D_SMA` | PRELIMINAR_REV_A | Sí: cátodo a `+12V_LOCK`, ánodo a `LOCK_OUT` | Confirmar encapsulado y banda; colocar junto a J9 |
| D9 | DNP según tipo de buzzer | `Diode_THT:D_DO-35_SOD27_P10.16mm_Horizontal` | PRELIMINAR_REV_A | Sí: pad 1=K | No montar hasta confirmar buzzer |
| BZ1 | Buzzer | `Buzzer_Beeper:Buzzer_12x9.5RM7.6` | PRELIMINAR_REV_A | Sí | Confirmar tipo, tensión, polaridad, altura y paso |
| J5 | RC522 externo | `Connector_PinHeader_2.54mm:PinHeader_1x08_P2.54mm_Vertical` | PRELIMINAR_REV_A | Sí, orden lógico 1–8 documentado | Verificar orientación física antes de conectar |
| J13 | ESP32-S3 DevKitC-1 N16R8 44P | `rfid_eest3:ESP32-S3-DevKitC-1-44P_PLACEHOLDER_NO_FABRICAR` | PLACEHOLDER_NO_FABRICAR | Sí, 44 pads unificados | Separación entre hileras usada: 25,4 mm provisional; no fabricar |
| J1, J6, J9–J12 | Borneras 2P 5,08 | `rfid_eest3:KF301_2P_P5.08_PLACEHOLDER_NO_FABRICAR` | PLACEHOLDER_NO_FABRICAR | Sí | Medir cuerpo, pin, tornillo y taladro; J1/J9 ≥5 A |
| J8 | Bornera 3P 5,08 | `rfid_eest3:KF301_3P_P5.08_PLACEHOLDER_NO_FABRICAR` | PLACEHOLDER_NO_FABRICAR | Sí | Medición física obligatoria |
| J2 | Bornera 4P 5,08 | `rfid_eest3:KF301_4P_P5.08_PLACEHOLDER_NO_FABRICAR` | PLACEHOLDER_NO_FABRICAR | Sí | Interfaz del buck externo; medición física obligatoria |
| C1 | 1000 µF / 25 V | `rfid_eest3:CP_Radial_D16_P7.50_PLACEHOLDER_NO_FABRICAR` | PLACEHOLDER_NO_FABRICAR | Sí, polarizado | Confirmar diámetro, altura, paso y fabricante |
| C3 | 470 µF / 10 V | `rfid_eest3:CP_Radial_D10_P5.00_PLACEHOLDER_NO_FABRICAR` | PLACEHOLDER_NO_FABRICAR | Sí, polarizado | Confirmar diámetro, altura, paso y fabricante |
| C9 | 10 µF preliminar | `rfid_eest3:CP_Radial_D5_P2.00_PLACEHOLDER_NO_FABRICAR` | PLACEHOLDER_NO_FABRICAR | Sí, geometría provisional | Pads ajustados a 1,6 mm para cumplir clearance; medir componente |
| NT1 | Unión estrella GND/GND_POWER | `NetTie:NetTie-2_THT_Pad1.0mm` | PRELIMINAR_REV_A | Sí | No sustituir por puente accidental |
| H1–H4 | Agujeros M3, Ø3,2 mm | `rfid_eest3:MOUNTING_HOLE_3.2_PLACEHOLDER_NO_FABRICAR` | PLACEHOLDER_NO_FABRICAR | No aplica | Posiciones provisionales; confirmar caja y separadores |
| D1, D5–D8 | Protección Schottky/TVS pendiente | Sin footprint | PENDIENTE_MEDICIÓN | No | Requiere componente y encapsulado definitivos |
| F1, F2 | Fusible/PTC pendiente | Sin footprint | PENDIENTE_MEDICIÓN | No | Requiere curva, corriente de arranque y encapsulado |

IRFZ44N continúa descartado para control directo a 3,3 V. Q2 conserva el
AO3400A preliminar: disipación fría calculada ≈0,156 W a 1,8 A y 48 mΩ,
pendiente de corriente de arranque, temperatura ambiente, cobre disponible y
ensayo térmico.

### Reglas y distribución provisional

| Clase | Redes principales | Ancho | Clearance | Vía / taladro |
|---|---|---:|---:|---:|
| `LOGIC` | GPIO, SPI, sensores y control | 0,25 mm | 0,20 mm | 0,80 / 0,40 mm |
| `POWER_3V3_5V` | `+3V3`, `+5V`, `GND` | 0,50 mm | 0,25 mm | Heredada provisional |
| `POWER_12V_AUX` | `+12V_IN`, `+12V_AUX` | 0,80 mm | 0,30 mm | Heredada provisional |
| `LOCK_POWER` | `+12V_LOCK`, `LOCK_OUT`, `GND_POWER` | 2,00 mm mínimo | 0,50 mm | Evitar; si fueran necesarias, varias en paralelo |

Para `LOCK_POWER` se prefiere 2,50 mm o cobre vertido, sujeto al cálculo
térmico y al stackup final. No se creó cobre ni se rutearon redes.

Contorno provisional: rectángulo de **120 × 80 mm**, con cuatro agujeros
provisionales de Ø3,2 mm. Zonas del floorplan:

- A: potencia/cerradura en el sector inferior izquierdo.
- B: alimentación lógica contigua, separada de `LOCK_OUT`.
- C: ESP32-S3 junto al borde derecho, antena orientada al borde superior.
- D: RC522/SPI en el borde superior izquierdo, opuesto a potencia.
- E: sensores y DSC LC-100 accesibles desde el borde inferior.
- F: LEDs y buzzer en el sector central, visibles y alejados de potencia.

Se crearon dos keepouts de antena, uno en F.Cu y otro en B.Cu, que prohíben
pistas, vías y cobre entre X=106,5…139,5 mm e Y=20,2…32 mm. No existen zonas
de cobre.

### Auditoría de colocación y DRC preliminar

- Footprints: **50** (46 eléctricos + 4 agujeros mecánicos).
- Redes: **57**.
- Pistas/segmentos: **0**.
- Vías: **0**.
- Zonas de cobre: **0**.
- Keepouts: **2**.
- Contorno: **120 × 80 mm**.
- Ratsnest aproximado de kicad-ai: **483 pares**.
- DRC de KiCad: **88 elementos no conectados**, esperados por ausencia de
  ruteo; no deben excluirse.
- Violaciones geométricas no relacionadas con ruteo: **20 advertencias de
  serigrafía** (9 solapamientos y 11 recortes por máscara). No hay errores de
  clearance después de ajustar el placeholder C9.
- `score_placement`: HPWL 1946,79 mm; congestión pico 2; proximidad de
  desacoplos 38,29 mm. Son métricas de prelayout, no aceptación para fabricar.
- No se detectaron courtyards fuera del contorno; NT1 carece de courtyard.
- La miniatura automática no estuvo disponible en la herramienta.

Las advertencias de serigrafía se conservan documentadas porque varias nacen
de placeholders que serán reemplazados. Deben resolverse al confirmar
footprints y antes de cualquier salida de fabricación; no se crearon
exclusiones DRC.

### Mediciones físicas aún necesarias

- ESP32-S3: separación entre hileras, largo/ancho/altura, USB-C, botones,
  borde de antena y posición de pines.
- RC522: orientación real del header, dimensiones, cable y separación de
  antena respecto de cobre/metal.
- Borneras: cuerpo, altura, diámetro de pin/taladro, acceso de tornillo,
  sección de cable y corriente nominal; J1/J9 deben admitir al menos 5 A.
- C1, C3 y C9: diámetro, altura, paso y polaridad.
- Buzzer: tipo activo/pasivo, magnético/piezoeléctrico, consumo y pinout.
- Caja: dimensiones internas, separadores, accesos, tolerancias y altura.
- Cerradura: corriente de arranque y temperatura de Q2 en operación.
- Protección: modelos/encapsulados de D1, D5–D8, F1 y F2.

### Puntos de prueba propuestos, no agregados

`+12V_IN`, `+12V_LOCK`, `+5V`, `+3V3`, `GND`, `GND_POWER`, `LOCK_GATE`,
`LOCK_OUT`, `RFID_SCK`, `RFID_MOSI`, `RFID_MISO`, `RFID_SS`, `PIR_IN` y
`PIR_TAMPER`.

Agregar estos puntos requiere autorización para modificar el esquema y una
nueva transferencia controlada.

## Snapshots

- Base: `20260729_051129_190283`.
- Raíz final: `20260729_053102_540897`.
- Alimentación: `20260729_053102_550681`.
- Controlador: `20260729_053102_563916`.
- RFID: `20260729_053102_572818`.
- Sensores: `20260729_053102_581116`.
- Señalización: `20260729_053102_589677`.
- Cerradura: `20260729_053102_597993`.
- Antes de actualizar alimentación: `20260729_055745_414782`.
- Antes de actualizar salida de cerradura: `20260729_055745_424431`.
- Alimentación actualizada: `20260729_061124_222735`.
- Salida de cerradura actualizada: `20260729_061126_968215`.
- Cerradura CC definitiva: `20260729_061551_779914`.
- Alimentación con protección 2,5 A preliminar: `20260729_061557_470129`.
- Raíz previa/final sin cambios: `20260729_053102_540897`.
- Controlador ESP32-S3 final: `20260729_070338_507833`.
- RC522 con resistencias serie y filtrado final: `20260729_070338_536833`.
- Sensores con `PIR_TAMPER`: `20260729_070338_557390`.
- Señalización sin cambios eléctricos: `20260729_055404_690955`.
- Cerradura sin cambios eléctricos: `20260729_061551_779914`.
- Alimentación con rama protegida `+12V_AUX`: `20260729_071440_883552`.
- Controlador con EN conectado mediante pull-up: `20260729_071440_909956`.
- Sensores con interfaz DSC LC-100 por contactos NC: `20260729_071440_967749`.
- PCB vacía previa a preparación de footprints: `20260729_072036_391223`.
- PCB transferida, previa a reglas y floorplan: `20260729_081110_872753`.
- PCB Rev. A con prelayout final: `20260729_082246_498656`.
- Señalización con Q1 AO3400A y D9 DNP: `20260729_073541_470080`.
- Sensores con PIR_PWR, PIR_ALARM y PIR_TAMPER separados: `20260729_073541_494917`.
- Cerradura con footprint SOT-23 verificado para Q2: `20260729_073541_519945`.
- Señalización final con datasheet de Q1: `20260729_073634_601985`.
- Sensores finales con terminales físicos pendientes documentados: `20260729_073634_619789`.

## Próximos pasos

1. En KiCad 10, usar **File → Revert** para recargar el esquema modificado.
2. Revisar visualmente las seis hojas.
3. Confirmar modelos y datasheets pendientes.
4. Confirmar numeración de borneras, cableado y ubicación del DSC LC-100.
5. No iniciar PCB hasta recibir la autorización textual requerida.

## Cierre de floorplan PCB Rev. A — 2026-07-29

- Rama de trabajo: `pcb-rev-a-prelayout`.
- Snapshot PCB previo a la reorganización: `20260729_180844_606658`.
- Snapshot PCB final: `20260729_181948_558376`.
- Esquema validado: siete archivos reconocidos, sin referencias duplicadas.
- ERC exacto: **0 infracciones**.
- PCB: **71 footprints**, **58 redes**, **0 pistas**, **0 vías** y
  **0 zonas de cobre**.
- Keepouts: **2**, uno en `F.Cu` y otro en `B.Cu`, para la antena.
- Contorno: `X=20…140 mm`, `Y=20…100 mm`, es decir **120 × 80 mm**.
- Bounding box de footprints: `X=21,9…138,9 mm`,
  `Y=20,5…99,8 mm`; ningún footprint queda fuera del contorno.
- H2 quedó en `(90, 25) mm`, a **16,5 mm** del comienzo del keepout de
  antena en `X=106,5 mm`.
- HPWL: **2493,32 mm** luego de la sincronización inicial y
  **2315,78 mm** después de reorganizar, mejora de 177,54 mm.
- Congestión pico: **2**.
- La métrica automática global de proximidad de desacoplos cambió de
  **49,57 mm** a **50,51 mm**. No se acepta como criterio de fabricación:
  mezcla capacitores de reserva y filtros con cargas no equivalentes.
  C6/C9 quedaron junto a J5; los filtros de sensores quedaron próximos
  al corredor hacia el ESP32; C1 está en la zona de potencia y C3 en la
  alimentación lógica. La validación definitiva depende de footprints y
  geometría física medidos.
- DRC de prelayout: **0 errores geométricos**, **0 solapamientos de
  courtyard**, **0 pads solapados**, **0 infracciones de keepout** y
  **117 conexiones sin rutear**, esperadas.
- Permanecen **10 advertencias `silk_over_copper`**, todas asociadas a
  gráficos internos de footprints preliminares/placeholders o marcadores
  de polaridad. No se creó ninguna exclusión. Deben corregirse al
  reemplazar los placeholders por footprints medidos, antes de fabricar.
- La advertencia extensa del RC522 y la nota del ESP32-S3 se trasladaron
  a `Dwgs.User`; no quedan solapamientos entre textos de serigrafía.
- El ESP32-S3 conserva estado `PLACEHOLDER_NO_FABRICAR`; los headers están
  dentro del contorno y la antena queda orientada hacia el borde superior.
- Miniatura generada:
  `rfid-control-acceso-eest3_thumbnail.svg`.

### Mediciones físicas bloqueantes antes de fabricar

- ESP32-S3: separación entre hileras, cuerpo, USB, botones, antena y
  extracción vertical con sockets.
- Borneras: taladro, cuerpo, acceso de tornillo, altura y corriente real;
  J1/J9 deben soportar al menos 5 A.
- C1, C3 y C9: diámetro, paso, altura y polaridad del componente comprado.
- Caja y agujeros H1–H4: separadores, cabeza de tornillo y accesos.
- Buzzer: tecnología, polaridad, consumo y necesidad de D9.
- Cerradura: corriente de arranque y temperatura de Q2.

## Correcciones aplicadas sobre la rama de auditoría

Fecha: 2026-07-29. Verificado regenerando el netlist con `kicad-cli`, no por
inspección visual.

### Errores eléctricos corregidos

- **D1 estaba invertido**: cátodo hacia `+12V_IN` y ánodo hacia F1, lo que
  bloquea la polaridad correcta. Con ese montaje la placa no encendía. Girado
  180°: ánodo en `+12V_IN`, cátodo hacia F1.
- **D2 y D3 estaban invertidos**: ánodo a `GND` y cátodo hacia R3/R4. Como un
  GPIO nunca baja de 0 V, los LEDs no podían encender. Girados 180°.
- **El tramo de mayor corriente estaba en la clase `Default`** (0,2 mm de pista)
  llevando ~2,2 A. La red entre D1 y F1 no coincidía con ningún patrón de
  netclass. Asignada a `LOCK_POWER` (2,0 mm), igual que `+12V_IN`, que estaba
  en `POWER_12V_AUX` (0,8 mm).
- Al girar los LEDs, KiCad renombró las redes autogeneradas
  (`Net-(D2-K)` → `Net-(D2-A)`). Las netclasses apuntaban a los nombres viejos
  y quedaban huérfanas; se re-apuntaron.

### ERC: alcance real de la verificación

El informe presentaba «0 errores y 0 advertencias» como resultado de
validación. No lo es: el proyecto no tiene ningún símbolo `power:` y de los 173
pines, 171 son `passive` y 2 son `input`. No hay pines de tipo power ni output,
así que la matriz de comprobación eléctrica del ERC no tiene nada que evaluar.
El resultado limpio está garantizado por construcción. La verificación útil de
este diseño es el netlist y la revisión de polaridades, no el ERC.

### Footprint del ESP32-S3

El módulo es un DevKitC-1 N16R8, cuyo form factor usa 22,86 mm entre hileras.
Como no se midió el ejemplar físico, el footprint duplica la hilera par en
22,86 y 25,40 mm: se suelda el zócalo solo en la que corresponda. Son 22
agujeros extra en un prototipo.

El paso doble cubre la separación, **no el orden de pines**. Todo el mapa GPIO
asume el orden del header J1 del DevKitC-1. Antes de soldar hay que verificar
por continuidad 3V3, EN, 5V y GND contra la serigrafía del módulo: si el orden
está corrido o espejado se mete 5 V en un GPIO.

Los pines 2, 42 y 44 (GND) tienen dos pads candidatos; hay que unir cada par
con un tramo corto para que ambos agujeros queden a masa.

### Floorplan recalculado

La posición de los pines de J13 determina el orden de los bloques. Con el
módulo horizontal, la hilera de señal expone, de derecha a izquierda:
`3V3, 3V3, EN │ IO4–IO7 (sensores) │ IO15–IO18 (LEDs, buzzer, cerradura) │
IO9–IO13 (RFID) │ 5V, GND`. Los bloques se alinearon a ese orden.

| Métrica | Antes | Ahora |
|---|---:|---:|
| Lazo de potencia J1 ↔ J9 | 86,0 mm | 38,1 mm |
| Estrella de masa NT1 ↔ J1 | 60,2 mm | 9,3 mm |
| SPI: J5 ↔ pin MISO | ~70 mm | 8,7 mm |
| Reed: J6 ↔ pin IO4 | 56,7 mm | 47,0 mm |
| Antena ↔ tornillo H3 | — | 7,9 mm |

El contorno creció de 120 × 80 a 140 × 100 mm. A 120 × 80 la densidad de
componentes quedaba en 53 %, que es ruteable pero penoso en dos capas con
pistas de 2 mm; a 140 × 100 baja a 36 %. La caja todavía es
`PENDIENTE_MEDICIÓN`, así que el contorno no estaba atado a nada real. Es
reversible.

### Compromisos asumidos, no resueltos

- H3 queda a 7,9 mm de la zona de antena. Conviene tornillo de nylon o dejarlo
  sin poblar hasta definir la caja.
- J8 (sensor de gabinete, marcado como futuro) se movió al borde superior
  izquierdo: las cinco borneras de sensores no entraban en una sola fila sin
  invadir el agujero de montaje H4.
- `LOCK_GATE` recorre ~50 mm desde IO18 hasta Q2. Es aceptable para una
  compuerta lenta con 100 Ω en serie y pull-down de 10 kΩ, pero conviene
  alejarla de las señales de sensores al rutear.
- La separación RFID/cerradura en la placa quedó en 59,1 mm. El RC522 es
  externo: la restricción real es dónde queda el módulo y su antena en la caja,
  no dónde está J5.

## J5: interfaz al lector montado en el marco de la puerta

El RC522 va montado en el marco y se conecta por cable. El diseño ya lo
contemplaba —J5 nunca fue el lector, sino su conector— pero J5 estaba en el
medio de la placa, lo que obligaba al cable a cruzar por encima de todo el
board. Se movió al borde superior, junto a las borneras de sensores: todos los
cables que van hacia la puerta salen ahora por el mismo lado, y el borde
inferior queda reservado a potencia y cerradura.

El footprint pasó de `PinHeader_1x08_P2.54mm_Vertical` a
`Connector_JST:JST_XH_S8B-XH-A_1x08_P2.50mm_Horizontal`: conector con traba y
entrada lateral. Un header de 2,54 con jumpers dupont falla de forma
intermitente en algo que golpea cada vez que se abre la puerta. Si no se
consigue un cable XH de 8 vías, se puede volver al header con una sola línea en
`03_rfid_rc522.kicad_sch`, pero en ese caso hay que soldar los conductores
directamente a los pines.

La traza de SPI subió de 8,7 a 43,7 mm. No es un problema: con el reloj a 1 MHz
y las resistencias serie de 33 Ω, 44 mm de pista es irrelevante frente a los
20-40 cm de cable. El factor dominante es el cable, no la traza.

### Condiciones de instalación del lector

- **Longitud del cable**: hasta ~25 cm sin precauciones; entre 25 y 50 cm
  bajando el reloj SPI a 1 MHz o menos; por encima de 50-60 cm aparecen fallas
  intermitentes. La caja debe ir del lado interno, lo más cerca posible del
  marco.
- **Metal**: la antena del RC522 es una bobina y una chapa próxima se comporta
  como espira en cortocircuito. Montado directo contra un marco metálico el
  alcance cae de 3-4 cm a prácticamente cero. Hacen falta 1-2 cm de material no
  metálico detrás de la antena, o una caja plástica sobre el marco en lugar de
  embutirla en la chapa. Con marco de madera no aplica.
- **Desacoplo local**: agregar 10 µF + 100 nF en el extremo del lector, además
  de C6/C9 en la placa. El pico de corriente del RC522 al transmitir provoca
  caída sobre el cable.
- **Seguridad**: el lector queda del lado inseguro y sus líneas SPI son
  accesibles. No es el eslabón débil: el firmware compara UID contra
  `uids.txt`, y un UID de MIFARE Classic se clona con un teléfono. Si en algún
  momento se quiere seguridad real, el cambio es autenticación con clave en la
  tarjeta, no blindar el cable.

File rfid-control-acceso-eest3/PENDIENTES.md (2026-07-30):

# Lo que falta — RFID EEST3 Rev. A

La placa está ruteada y el DRC pasa sin infracciones. Eso significa que el
diseño es **coherente consigo mismo**, no que sea correcto: el DRC verifica
geometría, no que los componentes aguanten lo que se les va a pedir ni que el
módulo que compraste tenga la forma que dice el footprint.

Este archivo es la respuesta a "¿ya se puede mandar a fabricar?". Hoy la
respuesta es no, por tres bloqueos.

## Bloqueo 1 — J13 tiene la hilera par duplicada

**Es el único bloqueo puramente geométrico, y alcanza para arruinar el lote.**

El footprint tiene 66 pads en tres filas: la impar en y = 73,00 y **dos**
hileras pares, una en y = 95,86 (paso 22,86 mm) y otra en y = 98,40 (paso
25,40 mm). Están las dos porque nunca se midió el módulo físico. La serigrafía
lo avisa —"USAR UNA SOLA HILERA PAR"— pero una serigrafía no arregla una placa
fabricada.

Qué hay que hacer:

1. Conseguir el ESP32-S3 DevKit que se va a usar y medir con calibre la
   separación real entre las dos hileras de pines.
2. Editar `rfid_eest3:ESP32-S3-44P_SOCKET_DUAL_22.86_25.40` y borrar la hilera
   que no corresponda, junto con sus dos textos de referencia.
3. Reruteo local de lo que colgaba de esa hilera y DRC de vuelta.

Mientras las dos hileras existan, cualquier Gerber que se genere trae 22
agujeros de más.

## Bloqueo 2 — ninguna de las nueve mediciones está hecha

[CHECKLIST_PREPCB.md](CHECKLIST_PREPCB.md) tiene nueve ítems y ninguno tildado.
Los que bloquean de verdad son estos cuatro, porque de ellos dependen valores
de componentes que ya están puestos en la placa:

| Qué medir | De qué depende |
|---|---|
| Corriente de arranque de la cerradura | El calibre de F1 y el margen de las pistas de 2,0 mm |
| Consumo estacionario del conjunto | El dimensionado de F2 y del buck |
| Temperatura de Q2 en el peor caso | Si el SOT-23 alcanza o hay que ir a un encapsulado con disipación |
| Energía que tiene que absorber D4 | Si el SMA alcanza |

Los cuatro son mediciones de banco sobre el prototipo actual, no simulaciones.
Ninguna se puede deducir del esquema.

## Bloqueo 3 — la mecánica no está verificada

Ocho borneras (J1, J2, J6, J8, J9, J10, J11, J12) y el zócalo J13 **no tienen
modelo 3D asignado**. En el render aparecen como pads pelados. El DRC valida
sus courtyards, así que en el plano no se pisan, pero nadie miró todavía si los
cuerpos reales entran donde tienen que entrar.

Medidas concretas a confirmar contra las piezas que se vayan a comprar:

- **Tres de los cuatro agujeros de montaje tienen un componente cerca**, medido
  desde el borde del courtyard al centro del agujero:

  | Componente | Agujero | Distancia |
  |---|---|---:|
  | J6 (bornera) | H4 | 4,78 mm |
  | J8 (bornera) | H1 | 4,95 mm |
  | C1 (electrolítico ⌀ 16 mm) | H2 | 4,96 mm |

  En los tres entra un tornillo M3 con arandela (⌀ 6–7 mm). En ninguno entra un
  separador hexagonal o de nylon de 8 mm. El de C1 es el más incómodo de los
  tres: el capacitor es alto, así que no solo estorba el separador sino
  también el destornillador. H3 es el único agujero despejado.

  Si el montaje va sobre separadores —que es lo habitual en una caja— hay que
  correr esos tres componentes o los agujeros antes de fabricar.

- Las cinco borneras del borde superior están a 2,00 mm del canto. Hay que
  confirmar que el cable entra de frente sin pelear con la caja.

También falta definir la separación entre la antena del RC522 y las partes
metálicas de la caja, que es lo que dice el ítem 4 del checklist.

## No bloquea, pero conviene saberlo

- **Los pines 1 y 2 de J13 están sin conectar a propósito.** Caen dentro de las
  áreas de reglas de la antena del ESP32-S3 (x 147..159), donde el proyecto
  prohíbe cobre. Son los tres únicos "no conectados" del DRC y no son un error:
  los rieles entran por el pin 3 (`+3V3`) y por 42/43/44 (`GND`). Meter cobre
  bajo la antena sería peor que dejar el pin libre.
- **`plano_gnd` quedó partido en 8 islas**, cada una conectada por pista. El
  retorno funciona y el DRC lo acepta. Un plano entero sería mejor, pero
  unirlas implica reordenar señales en B.Cu, o sea rehacer el ruteo.
  `plano_gnd_power`, que es el que lleva los 1,8 A, sí quedó de una pieza.

## Qué ya está resuelto

Para que nadie vuelva a abrir estos temas:

- Clases de red: los anchos del `.kicad_pro` coinciden con el cobre de la placa
  (2,0 mm potencia, 1,0 mm `+12V_AUX`, 0,8 mm alimentación lógica, 0,4 mm
  señal).
- Lazo de recirculación de la cerradura: D4 se movió al lado de J9 y las dos
  ramas bajaron de 15,8 y 14,7 mm a 6,97 mm cada una. Ver
  [GUIA_RUTEO.md](GUIA_RUTEO.md).
- Alivios térmicos: J5 pad 6 y J2 pad 4 pasaron a conexión sólida a plano.
- Serigrafía: sin superposiciones ni textos sobre cobre.
- La contradicción entre [AGENTS.md](../AGENTS.md) y el hecho de que la placa
  se ruteó con autorouter: aclarada en ese archivo.

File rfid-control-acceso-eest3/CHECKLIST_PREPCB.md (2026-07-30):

# Checklist de depuración pre-PCB

## Estado: ningún ítem tildado, y la PCB ya existe

Conviene decirlo de entrada porque cambia cómo se lee el resto del documento.
Este checklist se escribió como condición para *empezar* la PCB. La placa se
emplazó y se ruteó igual, con autorización explícita, y hoy pasa el DRC sin
infracciones.

Eso no invalida el checklist: lo reubica. Las mediciones que están acá abajo
seguían siendo necesarias antes y siguen siéndolo ahora, con la diferencia de
que ahora hay una placa concreta contra la cual medirlas en vez de una
estimación. Lo que **no** se puede hacer sin ellas es fabricar.

El criterio de pase del final de este archivo queda vigente tal cual, corrido
un casillero: ya no es el permiso para empezar el layout, es el permiso para
mandar a fabricar. La lista completa de bloqueos está en
[PENDIENTES.md](PENDIENTES.md).

## Objetivo

Convertir el diseño actual en un prototipo de laboratorio con mayor robustez eléctrica y menor riesgo de falla antes de avanzar a una PCB de prueba.

## Bloqueadores técnicos prioritarios

1. Alimentación y protección
   - Verificar que la fuente de 12 V tenga margen real para la cerradura y la electrónica.
   - Definir fusible o PTC con base en mediciones reales de corriente y arranque.
   - Separar físicamente la ruta de potencia de la cerradura del retorno lógico.

2. Etapa de cerradura
   - Medir corriente de arranque de la cerradura y consumo estacionario.
   - Validar el MOSFET con margen térmico, SOA y conducción a gate de 3,3 V.
   - Confirmar el flyback, su ubicación y su capacidad para absorber energía sin dañar el interruptor.

3. Interfaz con el controlador y sensores
   - Confirmar el pinout físico del ESP32-S3 y del módulo RC522.
   - Validar que la alimentación de 3,3 V sea estable bajo carga del RC522.
   - Revisar el comportamiento de los contactos secos y la lógica de seguridad frente a fallos de cableado.

4. Manufactura y montaje
   - Confirmar conectores, borneras y paso físico real antes de asignar footprints.
   - Definir separación entre antena RFID, cerradura, buck y partes metálicas.
   - Revisar que la caja y el montaje no comprometan la antena ni la disipación térmica.

## Lista de verificación

- [ ] Medir corriente de arranque de la cerradura.
- [ ] Medir consumo estacionario del sistema completo.
- [ ] Verificar tensión de 12 V, 5 V y 3,3 V bajo carga dinámica.
- [ ] Verificar temperatura del MOSFET en el peor caso de activación.
- [ ] Confirmar el flyback y protección de sobrecorriente con el componente real.
- [ ] Validar el pinout físico del ESP32-S3 y RC522.
- [ ] Definir la fuente definitiva de 12 V con margen suficiente.
- [ ] Confirmar borneras y conectores con capacidad real de corriente.
- [ ] Documentar resultados y actualizar el informe de diseño.

## Criterio de pase para mandar a fabricar

Se considera que el diseño está listo solo cuando:

- la fuente de alimentación no cae durante la activación de la cerradura;
- el MOSFET no supera temperatura crítica;
- el RC522 funciona sin reinicios ni interferencia visible;
- los conectores y la mecánica están confirmados físicamente;
- el esquema y la documentación están alineados con los datos medidos.

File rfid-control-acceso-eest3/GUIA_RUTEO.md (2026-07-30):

# Guía de ruteo — RFID EEST3 Rev. A

Escrita para esta placa en concreto. No es un tutorial general de KiCad.

## Qué es rutear

Ahora mismo el board tiene los componentes colocados y **122 líneas finas**
que van de un pad a otro. Eso se llama *ratsnest*: son las conexiones que el
esquema dice que tienen que existir, pero que todavía no tienen cobre.

Rutear es dibujar el cobre que reemplaza esas líneas. Cada vez que conectás
dos pads, la línea correspondiente desaparece. Ese contador de abajo a la
derecha —**Sin enrutar: 122**— es tu barra de progreso. Terminaste cuando
llega a 0.

Hay dos caras de cobre: **F.Cu** (frente, rojo) y **B.Cu** (dorso, azul). Una
**vía** es un agujerito metalizado que pasa una pista de una cara a la otra.

## Lo único que tenés que saber de la interfaz

| Tecla | Qué hace |
|---|---|
| `X` | Empieza a rutear desde el pad que está bajo el cursor |
| clic | Fija una esquina y sigue |
| `End` o doble clic | Termina la pista ahí |
| `Esc` | Cancela la pista que estás dibujando |
| `V` | Mientras ruteás: pone una vía y sigue por la otra cara |
| `Re Pág` / `Av Pág` | Cambia la cara activa (F.Cu / B.Cu) |
| `D` | Arrastra una pista sin desconectarla |
| `U` | Selecciona toda la pista conectada (para borrarla entera) |
| `Supr` | Borra lo seleccionado |
| `/` | Cambia el sentido del codo de 45° |
| `Ctrl+Z` | Deshacer |
| `B` | Rellena todas las zonas de cobre |

Si alguna no coincide, están todas en Preferencias → Atajos de teclado.

### El ancho ya está resuelto

No tenés que elegir el ancho de ninguna pista. En la barra superior dice
**"Pista: usar el ancho de clase de nodo"**, o sea que KiCad toma el ancho de
la clase de red. Dejalo así. Cada red ya tiene el suyo asignado:

- **2,0 mm** las de potencia (llevan 1,8 A)
- **1,0 mm** `+12V_AUX`
- **0,8 mm** las de alimentación lógica (`+3V3`, `+5V`, `GND`)
- **0,4 mm** las de señal

La única excepción legítima son los **tramos de transición** en pads de SOT-23:
la fuente y el drain de Q2 miden 0,6 mm de ancho y ninguna pista de 2 mm sale
de ahí sin pisar el pad de al lado. Se sale con 0,6–1,0 mm por uno o dos
milímetros y se ensancha en cuanto el encapsulado lo permite.

Si en algún momento ves que una pista de potencia te sale finita, es que la
clase de red no se aplicó: pará y avisá antes de seguir.

### El modo del router

Barra superior del router: dejalo en **"Empujar"** (Shove). Cuando una pista
nueva choca con una existente, la corre sola en lugar de bloquearte.

## El orden importa

Ruteá de lo más restringido a lo más libre. Las pistas de 2 mm casi no tienen
margen de maniobra; las de señal pasan por cualquier lado. Si dejás la
potencia para el final, no te va a entrar.

### Fase 1 — Potencia (2,0 mm, esquina inferior izquierda)

| Orden | Red | Pads | Recorrido |
|---:|---|---:|---|
| 1 | `+12V_IN` | 3 | J1 pin 1 → D1 ánodo, y TP1 |
| 2 | `Net-(D1-K)` | 3 | D1 cátodo → F1 |
| 3 | `+12V_LOCK` | 10 | F1 → C1, C2, D5, J9, D4, J2, F2, TP2 |
| 4 | `GND_POWER` | 8 | J1 pin 2 → C1, C2, D5, Q2 source, R8, NT1, TP6 |
| 5 | `LOCK_OUT` | 4 | J9 pin 2 → Q2 drain, D4, TP8 |

**Lo más importante de toda la placa** está en los pasos 3 a 5. La cerradura
es una bobina: cuando Q2 la apaga, la corriente tiene que seguir circulando y
se va por D4. Ese lazo —J9 → D4 → Q2 → vuelta— tiene que ser **lo más chico
posible**. Ruteálo corto y compacto, aunque quede feo. Si ese lazo es grande,
genera picos de tensión que pueden resetear el ESP32 o romper el MOSFET.

`GND_POWER` es el retorno de los 1,8 A. Va solo por esta esquina. **No lo
conectes a `GND` en ningún lado**: se tocan únicamente en NT1, que está pegado
a J1 justamente para eso.

### Fase 2 — Alimentación lógica (0,8 mm)

| Orden | Red | Pads |
|---:|---|---:|
| 6 | `+5V` | 8 |
| 7 | `+3V3` | 13 |
| 8 | `+12V_AUX` | 2 |

`+3V3` sale del DevKit (J13 pines 1 y 3) y alimenta el RC522, los pull-ups y
J8. `+5V` viene del buck por J2 y entra al DevKit por el pin 41.

### Fase 3 — Masa lógica: usá un plano, no pistas

`GND` tiene 34 pads. Rutearlos uno por uno a mano es una tortura innecesaria.
Se hace con un **plano de cobre** (zona rellena):

1. Poné la cara activa en **B.Cu** (`Av Pág`).
2. Herramienta **"Añadir zona rellena"** (barra derecha) o `Ctrl+Shift+Z`.
3. Dibujá un contorno en **L**: todo el ancho de y=21 a y=79, y además la
   franja de x=89 a x=159 hasta y=119. Esa segunda parte es la que cubre al
   DevKit, que está abajo a la derecha (x 96..150, y 73..98) y quedaría afuera
   de un simple rectángulo superior.
4. En el diálogo elegí la red **GND** y aceptá.
5. Presioná `B` para rellenar.

Todos los pads de GND que caigan adentro quedan conectados solos, con sus
patitas térmicas. Vas a ver el contador de "sin enrutar" desplomarse.

**Por qué el plano no baja hasta abajo:** la esquina inferior izquierda es la
de potencia. Si el plano de masa lógica se metiera ahí, el retorno de 1,8 A de
la cerradura compartiría cobre con la masa del ESP32, que es exactamente lo
que este diseño evita. El plano se queda arriba, y la unión con la masa de
potencia se hace en un solo punto:

6. Ruteá **una** pista de 0,8 mm desde el pad 2 de NT1 hasta el plano.

Esa pista es la estrella de masa. Es la única.

La esquina de potencia lleva su propio plano, `GND_POWER`, de x=21 a x=87 y de
y=80,5 a y=118. Entre los dos planos quedan 1,5 mm de hueco: se tocan sólo a
través de NT1. Los dos los pone [tools/planos_masa.py](../tools/planos_masa.py).

### Fase 4 — Señales (0,4 mm)

Las 25 redes restantes, casi todas de 2 o 3 pads. Acá ya es relleno: van por
F.Cu y donde no puedan, una vía y siguen por B.Cu.

Dos detalles:

- **RFID_SS, SCK, MOSI, RST** salen de J13, pasan por R9–R12 y siguen a J5.
  Mantenelas juntas y parejas, sin desvíos raros.
- **LOCK_GATE** va de J13 hasta Q2 y son unos 50 mm. Tratá de que no corra
  pegada y en paralelo a las señales de sensores por tramos largos.

### Los pads dobles de J13

J13 tiene la hilera par duplicada en 22,86 y 25,40 mm, porque no medimos el
módulo. Los pines **2, 42 y 44** son GND y por eso tienen **dos pads cada
uno**. Uní cada par con un tramo corto de cobre, si no el DRC te los va a
marcar como no conectados. Los demás pines duplicados no tienen red y no hay
que tocarlos.

El **pin 2 es la excepción**: cae dentro del área de reglas de la antena y no
se puede unir con cobre. Queda sin conectar a propósito; la masa del módulo
entra por los pines 42, 43 y 44.

## Cómo saber que vas bien

- El contador **"Sin enrutar"** baja y no vuelve a subir.
- Corré el **DRC** (Inspeccionar → Comprobador de reglas de diseño) cada
  tanto, no solo al final. Es mucho más fácil arreglar un choque recién hecho
  que quince juntos.
- Las de serigrafía (`silk_overlap`) ignoralas hasta el final: son textos
  pisándose, no afectan el cobre.

## Si te trabás

- **No entra una pista**: en vez de forzarla, poné una vía (`V`), pasá a la
  otra cara, cruzá por abajo y volvé a subir con otra vía. Es normal y no
  tiene nada de malo.
- **Una pista quedó horrible**: `U` para seleccionarla entera, `Supr`, y de
  nuevo. Borrar y rehacer es más rápido que corregir.
- **Moviste algo sin querer**: `Ctrl+Z`. Y guardá seguido.

Nada de lo que hagas acá es irreversible mientras no se fabrique. Equivocarse
ruteando no rompe nada.

## Cómo se ruteó esta placa

Está ruteada. **348 pistas, 8 vías, 4 zonas** (dos planos y las dos áreas de
reglas de la antena). El DRC pasa **sin ninguna infracción**: no quedan avisos
de margen, de cobre, de alivio térmico ni de serigrafía. Los únicos tres
"no conectados" son deliberados y están explicados abajo.

Las fases de arriba quedan como referencia de por qué el cobre está donde está,
y para cuando haya que retocar a mano.

Se hizo con **Freerouting 2.2.4** (en `~/.local/opt`, con su propio Java; el
comando `freerouting` abre la GUI, que no hace falta). El ida y vuelta con
KiCad va por [tools/autorutear.py](../tools/autorutear.py), que exporta a
Specctra DSN, rutea y reimporta el `.SES` sin abrir la interfaz.

**El orden de los pasos no es negociable:**

```sh
python3 tools/preruteo_critico.py <placa>   # 1. lo que el autorouter no puede
tools/autorutear.py <placa> --en-sitio      # 2. las 122 conexiones
python3 tools/planos_masa.py <placa>        # 3. los dos planos, al final
python3 tools/lazo_flyback.py <placa>       # 4. la esquina de potencia a mano
python3 tools/retoques_finales.py <placa>   # 5. térmicas y serigrafía
```

Los pasos 4 y 5 corrigen cosas que el autorouter no tiene forma de saber: que
el diodo de recirculación va pegado a la carga aunque el ruteo más corto diga
otra cosa, y que un designador ilegible es un defecto aunque no sea cobre.
Los dos son idempotentes y se pueden correr solos sobre la placa ya ruteada.

### 1. Primero a mano, y bloqueado

Dos conexiones no las puede hacer ningún autorouter, y son las que definen si
la placa funciona — [tools/preruteo_critico.py](../tools/preruteo_critico.py):

- **Fuente de Q2 → plano `GND_POWER`.** La clase pide 2,0 mm y el pad del
  SOT-23 mide 0,6 mm: no hay pista de 2 mm que salga de ahí sin pisar el drain.
  Freerouting abandonaba justo el retorno de 1,8 A del MOSFET. Va con 1,0 mm y
  una vía de 0,8 mm que baja directo al plano.
- **`+3V3` del pin 3 de J13.** La fila impar del DevKit son 22 pads a 2,54 mm:
  entre dos contiguos quedan 0,74 mm y no pasa ni una pista de 0,25 mm con su
  margen. La única salida es por debajo del módulo, rodeando el extremo oeste
  (el este es área de antena, x ≥ 147, donde no se permite cobre). El +3V3 lo
  genera el DevKit, así que sin esto el RC522 no se alimenta.

Van **bloqueadas**: una pista bloqueada se exporta como `(type fix)` y
Freerouting no la toca. `autorutear.py` se niega a correr si encuentra pistas
sin bloquear, salvo que le pases `--forzar`.

### 3. Los planos al final, no al principio

Si los planos están puestos antes de autorutear, el autorouter cruza B.Cu con
señales, parte el plano en islas y deja **11 pads de masa colgados**. Con `GND`
ruteado como pistas, cada pad tiene su conexión propia y el plano se suma
encima. Intenté penalizar B.Cu con un `.rules`, pero Freerouting 2.2.4 **ignora
`-dr` en modo CLI**: con B.Cu desactivado da idéntico resultado.

`plano_gnd_power` queda entero (una sola isla): es el retorno de 1,8 A.
`plano_gnd` queda en 8 islas, cada una conectada por pista.

## El lazo de la cerradura, que se rehízo a mano

Freerouting dejó a D4 en (80,50 / 85,75), o sea **del lado opuesto de Q2
respecto del conector de carga**. Eléctricamente eso es lo peor que se podía
hacer con ese diodo, y el autorouter no tenía cómo saberlo: para él era un
ruteo válido y corto.

Cuando Q2 corta, la bobina de la cerradura no deja de conducir de golpe; fuerza
a su corriente a seguir circulando y la única salida es D4. Ese lazo tiene que
ser chico porque todo lo que encierra es inductancia parásita, y esa
inductancia aparece como un pico de tensión sobre el drain del MOSFET. Por eso
el diodo va pegado a la carga, no pegado al transistor.

Con el emplazamiento original la corriente salía de J9, bajaba hasta TP8,
cruzaba al este, subía, pasaba de largo el MOSFET y recién ahí entraba al
diodo. [tools/lazo_flyback.py](../tools/lazo_flyback.py) mueve D4 a
(65,58 / 81,95), justo arriba de J9 y con el mismo orden de pines, de modo que
el cátodo cae sobre el pin 1 y el ánodo sobre el pin 2:

| Rama | Antes | Ahora |
|---|---:|---:|
| `+12V_LOCK` (J9 pin 1 → D4 cátodo) | 15,78 mm | **6,97 mm** |
| `LOCK_OUT` (J9 pin 2 → D4 ánodo) | 14,72 mm | **6,97 mm** |

Quedan dos bajadas rectas y paralelas de 7 mm separadas 4,5 mm. La conexión del
ánodo al drain de Q2 va aparte, rodeando el encapsulado por el norte y el este,
justamente para no meter ese recorrido dentro del lazo.

## Lo que quedó pendiente

- **Los pines 1 y 2 de J13 están sin conectar, a propósito.** Caen dentro de
  las dos áreas de reglas de la antena del módulo (x 147..159), donde no se
  permite cobre. Son los tres únicos "no conectados" del DRC. Meter cobre bajo
  la antena de un ESP32-S3 es peor que dejar el pin libre: los rieles llegan
  por el pin 3 (`+3V3`) y por 42/43/44 (`GND`).
- **`plano_gnd` quedó en 8 islas**, cada una conectada por pista. Funciona y el
  DRC lo da por bueno, pero un plano entero sería mejor. Reducirlas exige
  reordenar señales en B.Cu, que es rehacer el ruteo.

Lo demás que figuraba acá como pendiente ya está resuelto: el lazo de la
cerradura (arriba), los dos avisos de alivio térmico —J5 pad 6 y J2 pad 4
pasaron a conexión sólida a plano— y los 28 `silk_overlap`.

Lo que **bloquea la fabricación** no es nada de esto y está aparte, en
[PENDIENTES.md](PENDIENTES.md).

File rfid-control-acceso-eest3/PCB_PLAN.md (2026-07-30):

# Plan de PCB para la rama claude

## Objetivo

Convertir el esquema actual en una placa de prueba coherente para controlar una puerta con RFID, PIR y solenoide de 12 V.

## Alcance de esta versión

- PCB de prueba de tamaño medio, con distribución modular.
- Bloque de alimentación en un lado.
- Bloque del controlador ESP32 y RFID en el centro.
- Bloque de sensores y señalización en un lado.
- Bloque de potencia para la solenoide en un extremo, con separación física y retorno de potencia.
- Diseño orientado a montaje experimental, no a fabricación industrial.

## Convenciones de diseño

- Mantener la alimentación de 12 V y la lógica de 3,3 V separadas físicamente.
- Colocar el MOSFET de la solenoide cerca del conector de carga y del diodo flyback.
- Mantener el RC522 alejado de la ruta de corriente de la solenoide y de la antena de la cerradura.
- Reservar un espacio claro para el módulo buck y para los conectores externos.
- Usar trazas anchas en la ruta de corriente de la solenoide.

## Estado

Esta versión busca dejar el proyecto en un estado de PCB abierto y revisable en KiCad, con una topología de prueba más ordenada que el prototipo previo.

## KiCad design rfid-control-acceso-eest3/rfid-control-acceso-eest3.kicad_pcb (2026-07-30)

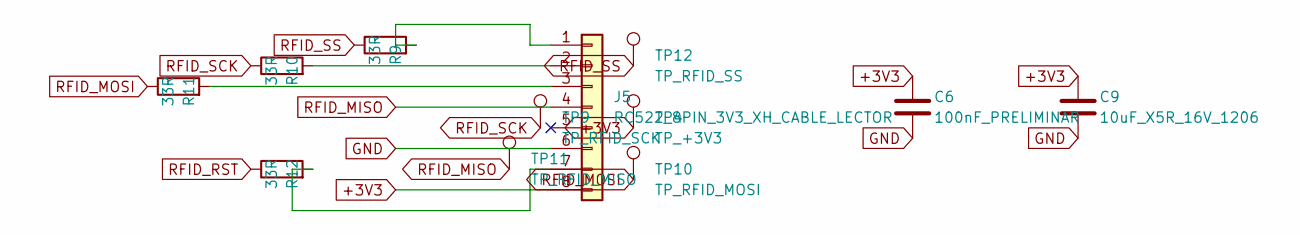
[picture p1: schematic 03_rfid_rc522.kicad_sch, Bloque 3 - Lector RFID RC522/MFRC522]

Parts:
C6: 100nF_PRELIMINAR; C_Disc_D5.0mm_W2.5mm_P5.00mm
C9: 10uF_X5R_16V_1206; C_1206_3216Metric
J5: RC522_8PIN_3V3_XH_CABLE_LECTOR; JST_XH_S8B-XH-A_1x08_P2.50mm_Horizontal
R9, R10, R11, R12: 33R; R_Axial_DIN0207_L6.3mm_D2.5mm_P10.16mm_Horizontal
TP4: TP_+3V3; TestPoint_THTPad_D2.0mm_Drill1.0mm
TP9: TP_RFID_SCK; TestPoint_THTPad_D2.0mm_Drill1.0mm
TP10: TP_RFID_MOSI; TestPoint_THTPad_D2.0mm_Drill1.0mm
TP11: TP_RFID_MISO; TestPoint_THTPad_D2.0mm_Drill1.0mm
TP12: TP_RFID_SS; TestPoint_THTPad_D2.0mm_Drill1.0mm

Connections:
+3V3: C6.1, C9.1, J5.8, TP4.1 (1_1); also elsewhere on the board
GND: C6.2, C9.2, J5.6; also elsewhere on the board
unnamed: J5.1, R9.2
unnamed: J5.2, R10.2
unnamed: J5.3, R11.2
unnamed: J5.7, R12.2
RFID_MISO: J5.4, TP11.1 (1_1); also elsewhere on the board
RFID_MOSI: R11.1, TP10.1 (1_1); also elsewhere on the board
RFID_RST: R12.1; also elsewhere on the board
RFID_SCK: R10.1, TP9.1 (1_1); also elsewhere on the board
RFID_SS: R9.1, TP12.1 (1_1); also elsewhere on the board

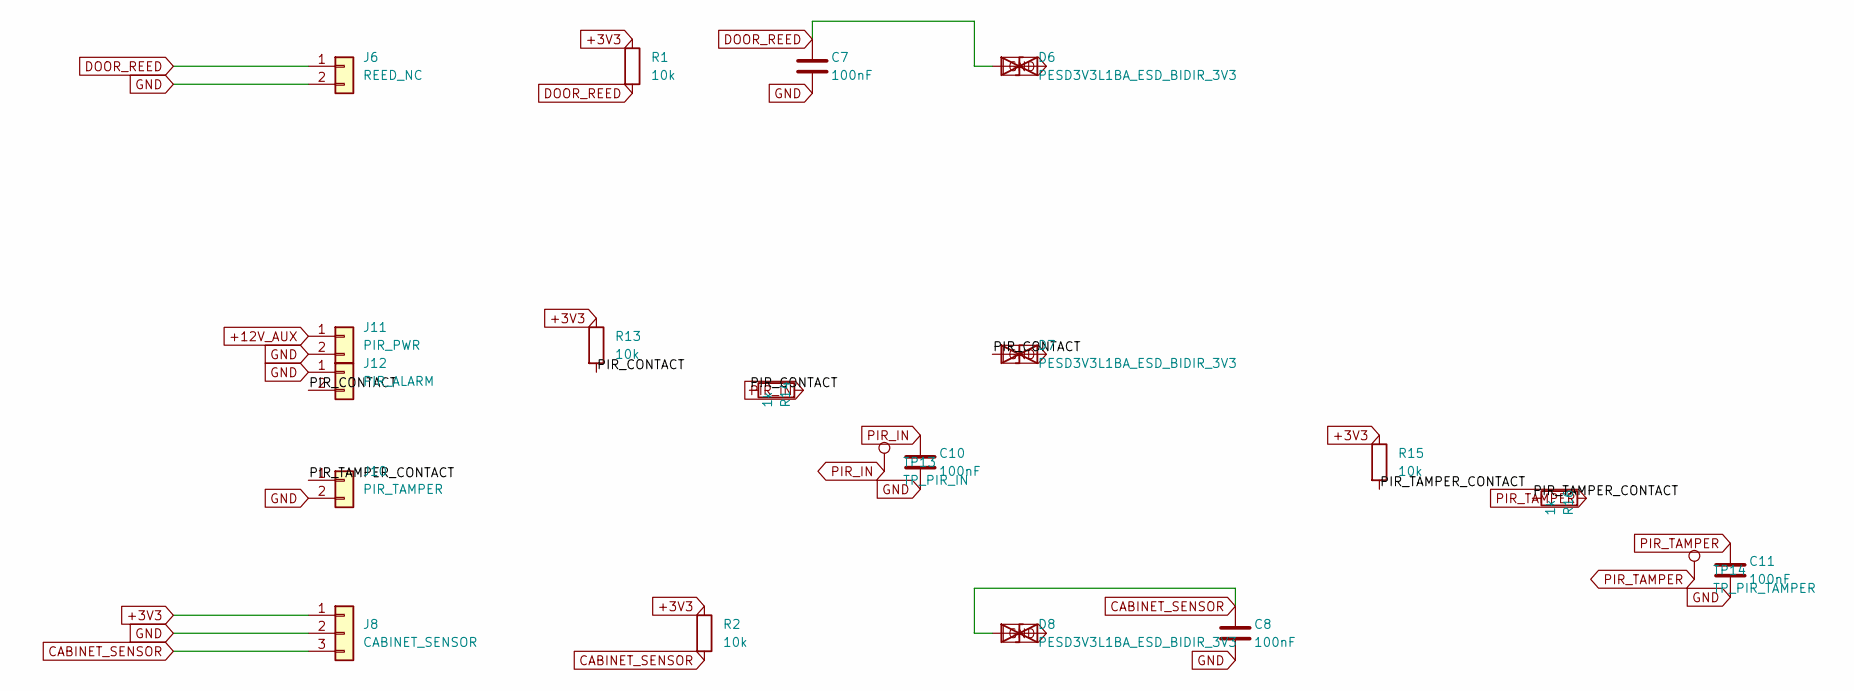
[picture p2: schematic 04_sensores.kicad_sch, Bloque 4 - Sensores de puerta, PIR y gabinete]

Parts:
C7, C8, C10, C11: 100nF; C_Disc_D5.0mm_W2.5mm_P5.00mm
D6, D7, D8: PESD3V3L1BA_ESD_BIDIR_3V3; D_SOD-323; MPN PESD3V3L1BA,115
J6: REED_NC; TerminalBlock_RND_205-00232_1x02_P5.08mm_Horizontal
J8: CABINET_SENSOR; TerminalBlock_RND_205-00233_1x03_P5.08mm_Horizontal
J10: PIR_TAMPER; TerminalBlock_RND_205-00232_1x02_P5.08mm_Horizontal
J11: PIR_PWR; TerminalBlock_RND_205-00232_1x02_P5.08mm_Horizontal
J12: PIR_ALARM; TerminalBlock_RND_205-00232_1x02_P5.08mm_Horizontal
R1, R2, R13, R15: 10k; R_Axial_DIN0207_L6.3mm_D2.5mm_P10.16mm_Horizontal
R14, R16: 1k; R_Axial_DIN0207_L6.3mm_D2.5mm_P10.16mm_Horizontal
TP13: TP_PIR_IN; TestPoint_THTPad_D2.0mm_Drill1.0mm
TP14: TP_PIR_TAMPER; TestPoint_THTPad_D2.0mm_Drill1.0mm

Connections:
+3V3: J8.1, R1.1, R2.1, R13.1, R15.1; also elsewhere on the board
+12V_AUX: J11.1; also elsewhere on the board
/4_SENSORES/PIR_CONTACT: D7.1 (A1), J12.2, R13.2, R14.1
/4_SENSORES/PIR_TAMPER_CONTACT: J10.1, R15.2, R16.1
CABINET_SENSOR: C8.1, D8.1 (A1), J8.3, R2.2; also elsewhere on the board
DOOR_REED: C7.1, D6.1 (A1), J6.1, R1.2; also elsewhere on the board
GND: C7.2, C8.2, C10.2, C11.2, D6.2 (A2), D7.2 (A2), D8.2 (A2), J6.2, J8.2, J10.2, J11.2, J12.1; also elsewhere on the board
PIR_IN: C10.1, R14.2, TP13.1 (1_1); also elsewhere on the board
PIR_TAMPER: C11.1, R16.2, TP14.1 (1_1); also elsewhere on the board

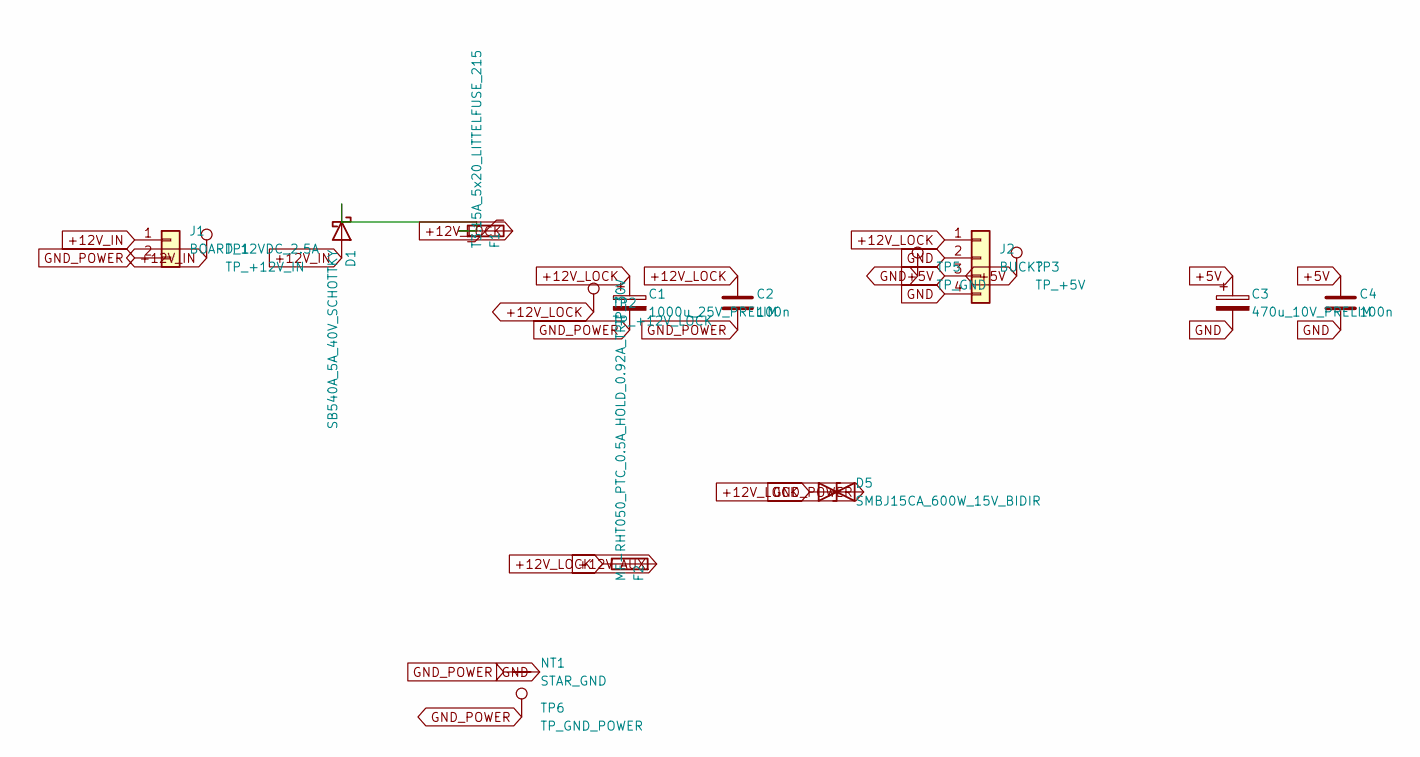
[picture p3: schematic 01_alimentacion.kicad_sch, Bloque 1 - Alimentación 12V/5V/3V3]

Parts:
C1: 1000u_25V_PRELIM; CP_Radial_D16.0mm_P7.50mm
C2, C4: 100n; C_Disc_D5.0mm_W2.5mm_P5.00mm
C3: 470u_10V_PRELIM; CP_Radial_D10.0mm_P5.00mm_P7.50mm
D1: SB540A_5A_40V_SCHOTTKY; D_DO-201AD_P15.24mm_Horizontal; MPN SB540A-E3/54
D5: SMBJ15CA_600W_15V_BIDIR; D_SMB; MPN SMBJ15CA
F1: T3.15A_5x20_LITTELFUSE_215; Fuseholder_Clip-5x20mm_Bel_FC-203-22_Lateral_P17.80x5.00mm_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; MPN 021503.15MXP + FC-203-22
F2: MF-RHT050_PTC_0.5A_HOLD_0.92A_TRIP_30V; Fuse_Bourns_MF-RHT050; MPN MF-RHT050
J1: BOARD_12VDC_2.5A; TerminalBlock_RND_205-00232_1x02_P5.08mm_Horizontal
J2: BUCK?; TerminalBlock_RND_205-00234_1x04_P5.08mm_Horizontal
NT1: STAR_GND; NetTie-2_THT_Pad1.0mm
TP1: TP_+12V_IN; TestPoint_THTPad_D2.0mm_Drill1.0mm
TP2: TP_+12V_LOCK; TestPoint_THTPad_D2.0mm_Drill1.0mm
TP3: TP_+5V; TestPoint_THTPad_D2.0mm_Drill1.0mm
TP5: TP_GND; TestPoint_THTPad_D2.0mm_Drill1.0mm
TP6: TP_GND_POWER; TestPoint_THTPad_D2.0mm_Drill1.0mm

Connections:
+5V: C3.1, C4.1, J2.3, TP3.1 (1_1); also elsewhere on the board
+12V_AUX: F2.2; also elsewhere on the board
+12V_IN: D1.2 (A), J1.1, TP1.1 (1_1)
+12V_LOCK: C1.1, C2.1, D5.1 (A1), F1.2, F2.1, J2.1, TP2.1 (1_1); also elsewhere on the board
GND: C3.2, C4.2, J2.2, J2.4, NT1.2, TP5.1 (1_1); also elsewhere on the board
GND_POWER: C1.2, C2.2, D5.2 (A2), J1.2, NT1.1, TP6.1 (1_1); also elsewhere on the board
unnamed: D1.1 (K), F1.1

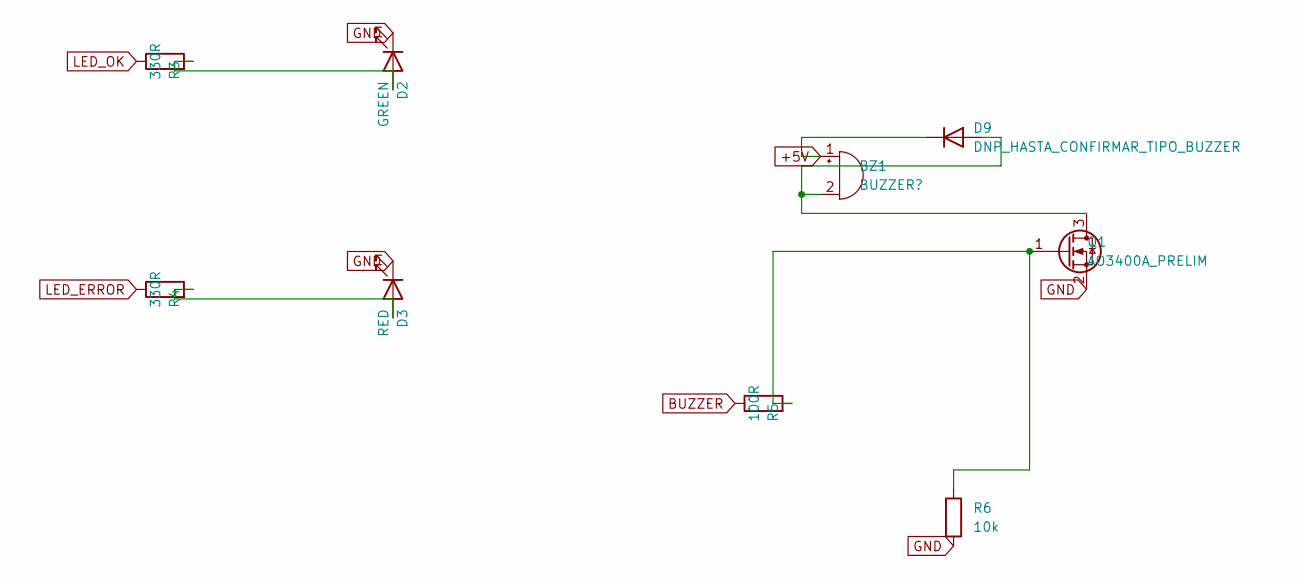
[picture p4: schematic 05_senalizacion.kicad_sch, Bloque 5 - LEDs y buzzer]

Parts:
BZ1: BUZZER?; Buzzer_12x9.5RM7.6
D2: GREEN; LED_D5.0mm
D3: RED; LED_D5.0mm
D9: DNP_HASTA_CONFIRMAR_TIPO_BUZZER; D_DO-35_SOD27_P10.16mm_Horizontal
Q1: AO3400A_PRELIM; SOT-23
R3, R4: 330R; R_Axial_DIN0207_L6.3mm_D2.5mm_P10.16mm_Horizontal
R5: 100R; R_Axial_DIN0207_L6.3mm_D2.5mm_P10.16mm_Horizontal
R6: 10k; R_Axial_DIN0207_L6.3mm_D2.5mm_P10.16mm_Horizontal

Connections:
+5V: BZ1.1 (+), D9.1 (K); also elsewhere on the board
BUZZER: R5.1; also elsewhere on the board
GND: D2.1 (K), D3.1 (K), Q1.2 (S), R6.2; also elsewhere on the board
LED_ERROR: R4.1; also elsewhere on the board
LED_OK: R3.1; also elsewhere on the board
unnamed: BZ1.2 (-), D9.2 (A), Q1.3 (D)
unnamed: D2.2 (A), R3.2
unnamed: D3.2 (A), R4.2
unnamed: Q1.1 (G), R5.2, R6.1

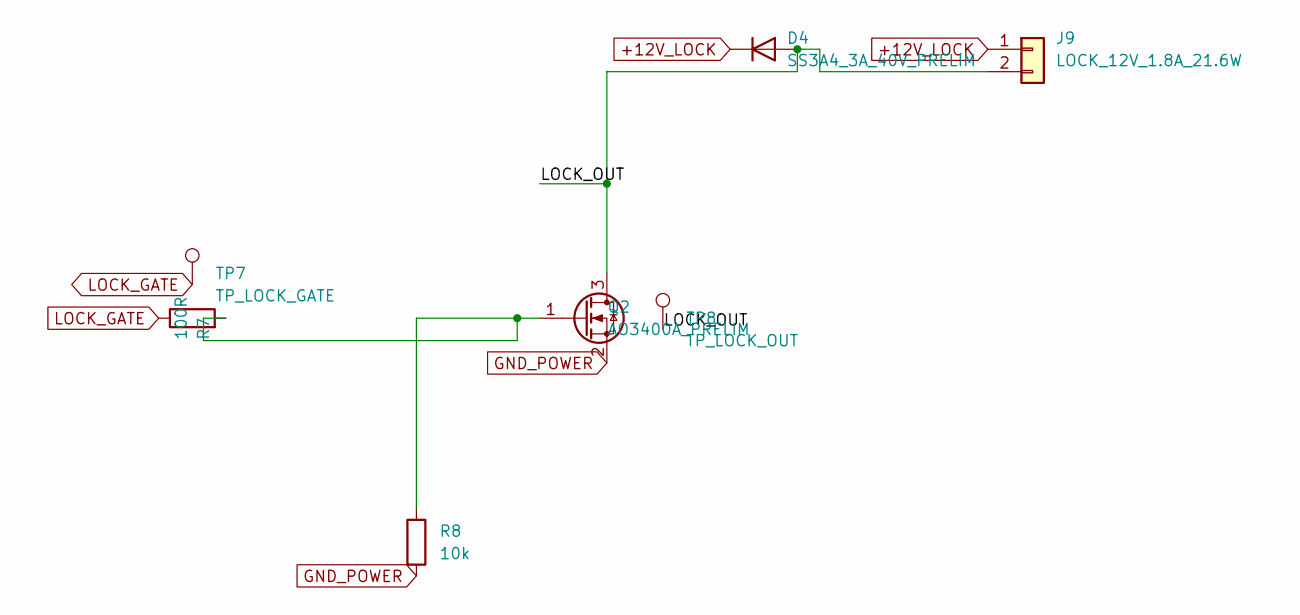
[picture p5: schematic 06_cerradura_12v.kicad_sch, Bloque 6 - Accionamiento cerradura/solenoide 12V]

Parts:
D4: SS3A4_3A_40V_PRELIM; D_SMA
J9: LOCK_12V_1.8A_21.6W; TerminalBlock_RND_205-00232_1x02_P5.08mm_Horizontal
Q2: AO3400A_PRELIM; SOT-23
R7: 100R; R_Axial_DIN0207_L6.3mm_D2.5mm_P10.16mm_Horizontal
R8: 10k; R_Axial_DIN0207_L6.3mm_D2.5mm_P10.16mm_Horizontal
TP7: TP_LOCK_GATE; TestPoint_THTPad_D2.0mm_Drill1.0mm
TP8: TP_LOCK_OUT; TestPoint_THTPad_D2.0mm_Drill1.0mm

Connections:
+12V_LOCK: D4.1 (K), J9.1; also elsewhere on the board
/6_CERRADURA_12V/LOCK_OUT: D4.2 (A), J9.2, Q2.3 (D), TP8.1 (1_1)
GND_POWER: Q2.2 (S), R8.2; also elsewhere on the board
LOCK_GATE: R7.1, TP7.1 (1_1); also elsewhere on the board
unnamed: Q2.1 (G), R7.2, R8.1

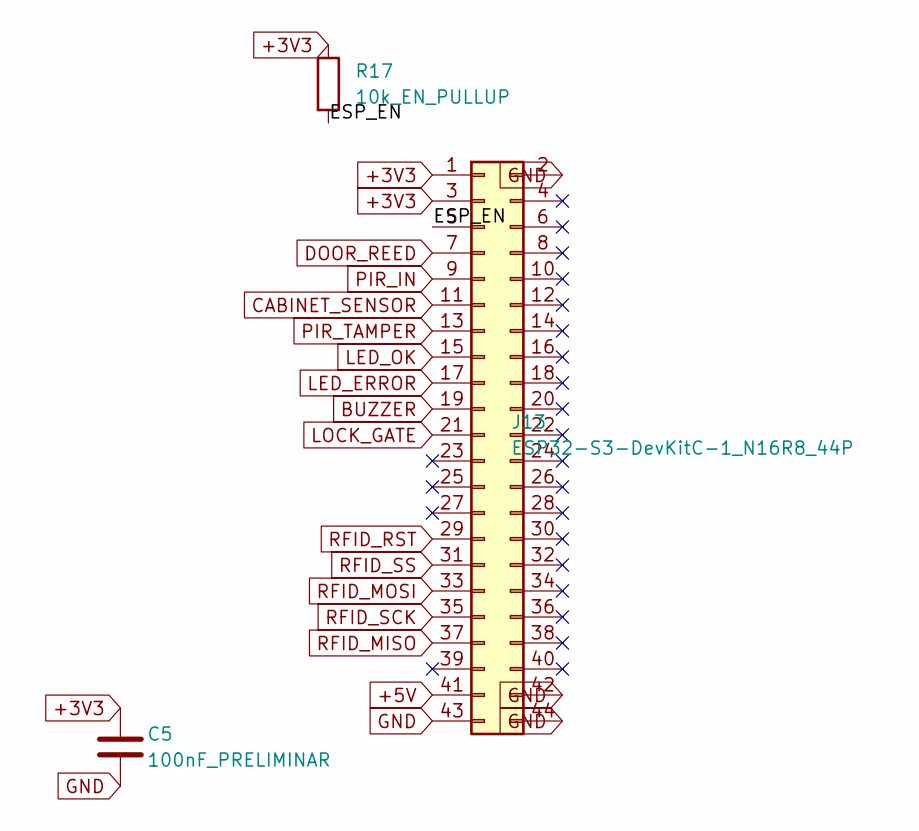
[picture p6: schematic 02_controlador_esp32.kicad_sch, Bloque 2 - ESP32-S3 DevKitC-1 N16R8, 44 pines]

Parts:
C5: 100nF_PRELIMINAR; C_Disc_D5.0mm_W2.5mm_P5.00mm
J13: ESP32-S3-DevKitC-1_N16R8_44P; ESP32-S3-44P_SOCKET_DUAL_22.86_25.40
R17: 10k_EN_PULLUP; R_Axial_DIN0207_L6.3mm_D2.5mm_P10.16mm_Horizontal

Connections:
+3V3: C5.1, J13.1, J13.3, R17.1; also elsewhere on the board
+5V: J13.41; also elsewhere on the board
/2_CONTROLADOR_ESP32/ESP_EN: J13.5, R17.2
BUZZER: J13.19; also elsewhere on the board
CABINET_SENSOR: J13.11; also elsewhere on the board
DOOR_REED: J13.7; also elsewhere on the board
GND: C5.2, J13.2, J13.42, J13.43, J13.44; also elsewhere on the board
LED_ERROR: J13.17; also elsewhere on the board
LED_OK: J13.15; also elsewhere on the board
LOCK_GATE: J13.21; also elsewhere on the board
PIR_IN: J13.9; also elsewhere on the board
PIR_TAMPER: J13.13; also elsewhere on the board
RFID_MISO: J13.37; also elsewhere on the board
RFID_MOSI: J13.33; also elsewhere on the board
RFID_RST: J13.29; also elsewhere on the board
RFID_SCK: J13.35; also elsewhere on the board
RFID_SS: J13.31; also elsewhere on the board

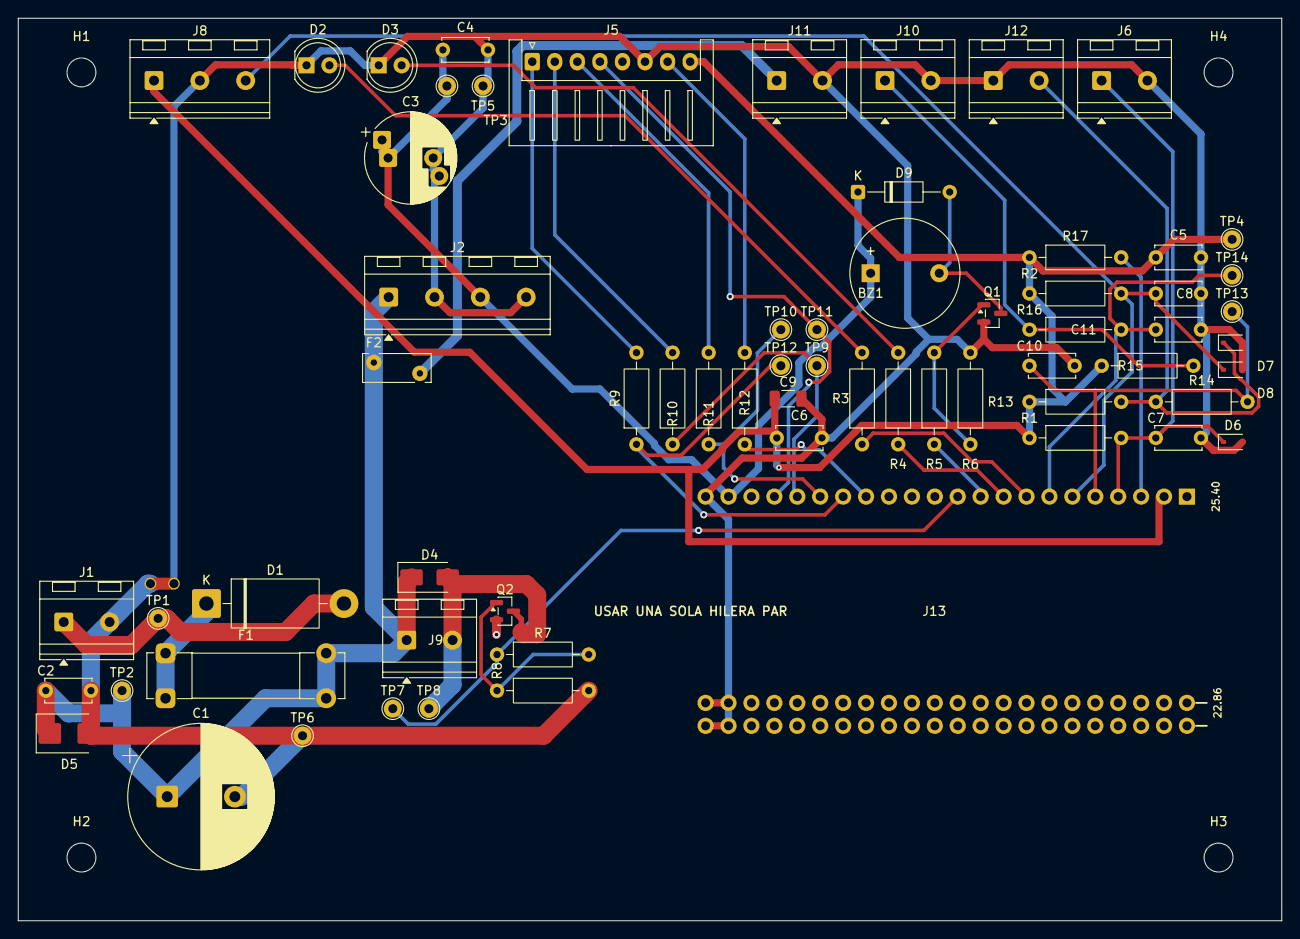
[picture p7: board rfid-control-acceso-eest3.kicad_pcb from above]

Board: 2 copper layers, 140.0 x 100.0 mm, 71 parts (0 on the bottom side), 34 nets.

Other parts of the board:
H1, H2, H3, H4: MOUNTING_HOLE_3.2_PROVISIONAL; MountingHole_3.2mm_M3

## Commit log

2026-07-29 Cierra esquema RFID ESP32-S3 con ERC limpio
    [01_alimentacion.kicad_sch, 02_controlador_esp32.kicad_sch, 03_rfid_rc522.kicad_sch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]
2026-07-29 Reorganiza floorplan PCB Rev A antes del ruteo
    [01_alimentacion.kicad_sch, 02_controlador_esp32.kicad_sch, 03_rfid_rc522.kicad_sch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]
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2026-07-30 Corrige tres diodos invertidos, netclasses y recalcula el floorplan
    Errores electricos, verificados regenerando el netlist con kicad-cli:
    - D1 tenia el catodo en +12V_IN y el anodo hacia F1, o sea bloqueaba la
    polaridad correcta. Montado asi la placa no encendia.
    - D2 y D3 tenian el anodo a GND y el catodo hacia R3/R4. Como un GPIO nunca
    baja de 0 V, los LEDs no podian encender.
    - La red entre D1 y F1 no coincidia con ningun patron de netclass y heredaba
    Default: 0,2 mm de pista para ~2,2 A. Pasa a LOCK_POWER (2,0 mm), igual que
    +12V_IN, que estaba en POWER_12V_AUX (0,8 mm).
    - Al girar los LEDs, KiCad renombro las redes autogeneradas. Las netclasses
    apuntaban a los nombres viejos;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
    [01_alimentacion.kicad_sch, 02_controlador_esp32.kicad_sch, 03_rfid_rc522.kicad_sch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]
2026-07-30 Lleva J5 al borde y le pone conector con traba para el lector del marco
    El RC522 va montado en el marco de la puerta y se conecta por cable. J5 estaba
    en el medio de la placa, asi que el cable tenia que cruzar por encima de todo
    el board. Se mueve al borde superior, junto a las borneras de sensores: todos
    los cables que van hacia la puerta salen por el mismo lado y el borde inferior
    queda para potencia y cerradura.
    El footprint pasa de PinHeader_1x08_P2.54mm_Vertical a JST_XH_S8B-XH-A
    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
    [03_rfid_rc522.kicad_sch, rfid-control-acceso-eest3.kicad_pcb]
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2026-07-30 Transfiere al board los footprints reales desde el esquema
    Resultado de Update PCB from Schematic en la GUI, que kicad-cli no expone.
    El board pasa a tener la geometria real: J13 con los 66 pads del footprint de
    doble paso (el pad 2 existe en x=22,86 y en x=25,40), J5 como JST-XH de 8 vias,
    C9 como 1206 y las ocho borneras como TerminalBlock_RND. Con esto los diodos
    D1, D2 y D3 quedan por fin conectados segun el esquema corregido.
    DRC: 28 infracciones, todas silk_overlap. Cero de biblioteca, cero de
    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
    [rfid-control-acceso-eest3.kicad_pcb]
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2026-07-30 Rutea la placa completa y ensancha las clases de red
    349 pistas, 8 vias y 4 zonas, sin infracciones de margen ni de cobre. Quedan
    3 no conectados: los pines 1 y 2 de J13, que caen dentro de las areas de
    regla de la antena del modulo y no se pueden alcanzar con cobre. Los rieles
    llegan por el pin 3 y por 42/43/44.
    El ruteo va en tres pasos, y el orden importa (tools/):
    1. preruteo_critico.py rutea a mano y bloquea las dos conexiones que ningun
    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
    [rfid-control-acceso-eest3.kicad_pcb]
2026-07-30 Acerca D4 a J9 y deja el DRC sin infracciones
    El emplazamiento dejaba a D4 en (80,50 / 85,75), del lado opuesto de Q2
    respecto del conector de carga. Freerouting no tenia como saber que eso esta
    mal: para el era un ruteo valido y corto.
    Cuando Q2 corta, la bobina de la cerradura no deja de conducir de golpe y su
    corriente se va por D4. Todo lo que ese lazo encierra es inductancia parasita,
    y esa inductancia aparece como pico de tension sobre el drain del MOSFET. Con
    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
    [rfid-control-acceso-eest3.kicad_pcb]
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2026-07-30 Guarda los bloques (units) que escribe KiCad 10 al abrir el board
    Cambio puramente aditivo generado por la GUI: 406 lineas, cero borradas, todas
    bloques (units) con el nombre de unidad y la lista de pines de cada huella. Son
    67, o sea todas menos los cuatro agujeros de montaje, que no tienen pines.
    No cambia geometria, pistas, posiciones ni reglas. Se commitea aparte y sin
    mezclar con nada para que el proximo diff del board vuelva a ser legible: si
    esto quedaba sin guardar, cualquier cambio real futuro aparecia enterrado bajo
    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
    [rfid-control-acceso-eest3.kicad_pcb]
2026-07-30 Agrega una hoja unica con todo el circuito
    La hoja raiz del proyecto son seis cajas vacias: ni un pin jerarquico ni un
    cable, porque los bloques se conectan por etiquetas globales. Abrirla no dice
    nada de como se relaciona una parte con otra, y para entender el circuito hay
    que ir saltando entre seis archivos.
    RESUMEN_ELECTRICO.kicad_sch es una hoja A2 con los 67 componentes, sus simbolos
    y sus valores, el cableado local de cada bloque y el ESP32 en el centro, que es
    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
    [RESUMEN_ELECTRICO.kicad_sch]
2026-07-30 Unifica el resumen en un solo recuadro con titulo y epigrafe
    La version anterior partia la hoja en seis cajas punteadas, una por bloque. Se
    leia como seis esquemas puestos uno al lado del otro y no como el circuito que
    son. Pasa a un unico recuadro con el titulo arriba y el nombre del esquema
    abajo, que es el formato de lamina que se usa para entregar.
    Los seis bloques siguen rotulados, pero ya sin caja propia: con 67 componentes
    hace falta saber donde empieza cada parte, y el rotulo solo alcanza para eso
    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
    [RESUMEN_ELECTRICO.kicad_sch]
2026-07-30 Cablea el resumen de punta a punta y saca las etiquetas de señal
    La version anterior tenia los bloques sueltos y unidos por etiquetas globales.
    Era el mismo mecanismo que usa el esquema de origen, pero para una lamina de
    una hoja no sirve: no se ve que va con que, hay que ir buscando el nombre
    repetido en la otra punta.
    Ahora hay cobre dibujado entre cada par de pines conectados. Cero etiquetas
    globales, 232 cables. El ESP32 pasa al margen izquierdo, girado para que su
    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
    [RESUMEN_ELECTRICO.kicad_sch]
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
